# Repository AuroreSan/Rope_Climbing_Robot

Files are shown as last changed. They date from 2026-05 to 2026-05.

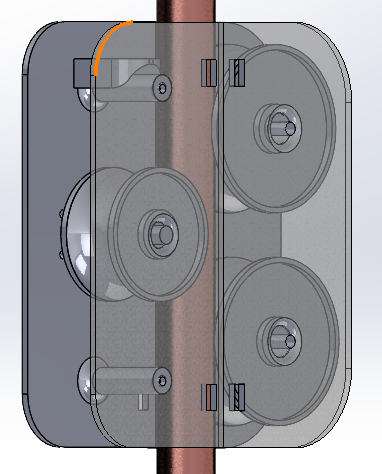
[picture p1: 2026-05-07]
w4.png

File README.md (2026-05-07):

# Rope Climbing Robot

A robotic system designed to autonomously climb ropes using 3D-printed components and motorized mechanisms.

## Overview

This project features a rope climbing robot with a modular body assembly, utilizing 3D printing technology with PLA or PETG materials for structural components. The robot is powered by 12V motors with H-bridge motor driver control.

## Assembly Instructions

### 3D Printed Components

Print the following STL files (without circuit cover):

| Component | Quantity | Infill |
|---|---|---|
| Back Body 1 Motor Placement | 1 | 15% |
| Front Body 1 Motor Placement | 1 | 15% |
| Front Body 2 Groove Wheel | 1 | 15% |
| Back Body 2 Groove Wheel | 1 | 15% |
| Motorised Pulley Wheel | 1 | 10% |
| Top Flat | 1 | 10% |
| Groove Wheel | 2 | 10% |
| M3 Body Pin Longer | 8 | 15% |
| Motor extension V3 | 8 | 25% |

#### Screws and Fasteners
- **2x** M3 Screw (10-20 mm) - Body assembly
- **4x** M3 Screw (50 mm) with nuts - Copper pipe connections
- **2x** M4 Screw (70 mm) - Front 2 and Back 2 body connections

#### Motors and Electronics
- **Motor:** 12V 107 RPM or 12V 200RPM
- **Motor Driver:** BTS7960 H-Bridge Motor Driver
- **Battery:** 12V 2400mAh NI-MH Rechargeable Battery with KET 2P Connection
- **LED:** 2 x (Red, Green) 
- **Passive Buzzer** 
- **Microcontroller:** Arduino nano 
- **Fuse:** L-12 Fuse Lamp 8V 250mA light Bulb or 10mA Fuse 
- **Switch:** 2 Push bottoms that can change the task of robot
- **Sensor** Time-of-Flight (ToF) Laser Ranging Sensor

*See the BOM (Bill of Materials) file for complete electronic components and specifications and link to the UK components*

## Assembly Steps

1. **Prepare 3D Printed Parts**
   - Ensure all printed components are clean
   - Verify proper fit of all mating surfaces

2. **Body Assembly**
   - Connect Front body 1 and Back body 1 using M3 screw of 20mm length 
   - Connect Front Body 2 and Back Body 2 using the M4 (50mm/70mm length). Make sure to put 2 big groove wheel in Body 2 before adding the scews. 

3. **Cross Body Connection**
   - Connect front and back body sections using 4x M4 70mm screws

5. **Motor and Pulley Assembly**
   - Mount the 12V 107 RPM motor on back Body 1. 
   - Install the motorised pulley wheel with the motor extension V3 inside
   - Cover all the wheels with non-slip mat cut off for better grip

6. **Electronics Integration**
   - Install BTS7960 H-Bridge Motor Driver
   - Connect motor power and control circuits per BOM specifications
   - Mount circuit components as specified in electronic assembly guide

## Bill of Materials (BOM)

Refer to the BOM document for a complete list of all electronic components and specifications.

## Design Features

- **Lightweight Construction:** 3D-printed PLA/PETG components reduce overall weight
- **Modular Assembly:** Separate front and back body sections allow for easy maintenance and customization
- **Efficient Drive System:** Motorised pulley with groove wheels for secure rope grip

## Project Structure

```
Rope_Climbing_Robot/
├── STL_Files/           # 3D printable model files
├── Electronics/         # Motor driver and control schematics
├── BOM.md              # Bill of materials
├── Assembly_Guide/     # Detailed assembly documentation
└── README.md           # This file
```

## Getting Started

1. Review and prepare all STL files for 3D printing
2. Print components 
3. Gather all hardware components listed in the BOM
4. Follow the assembly steps sequentially
5. Test motor operation before full deployment on rope

## Notes

- Ensure M3 and M4 fasteners are properly torqued but not over-tightened
- Verify motor rotation direction after assembly
- Test rope climbing functionality on a secured test rope before deployment

---

For questions or contributions, please refer to the project documentation or create an issue in the repository.

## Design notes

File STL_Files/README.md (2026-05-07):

# STL Files Directory

This directory contains all 3D printable STL model files for the Rope Climbing Robot project.

## Files to Add:
- Back Body 1 Motor Placement
- Front Body 1 Motor Placement
- Front Body 2 Groove Wheel
- Back Body 2 Groove Wheel
- Motorised Pulley Wheel
- Top Flat
- Groove Wheel
- M3 Body Pin Longer
- Motor extension V3

See README.md for printing specifications (infill percentages, quantities, etc.)

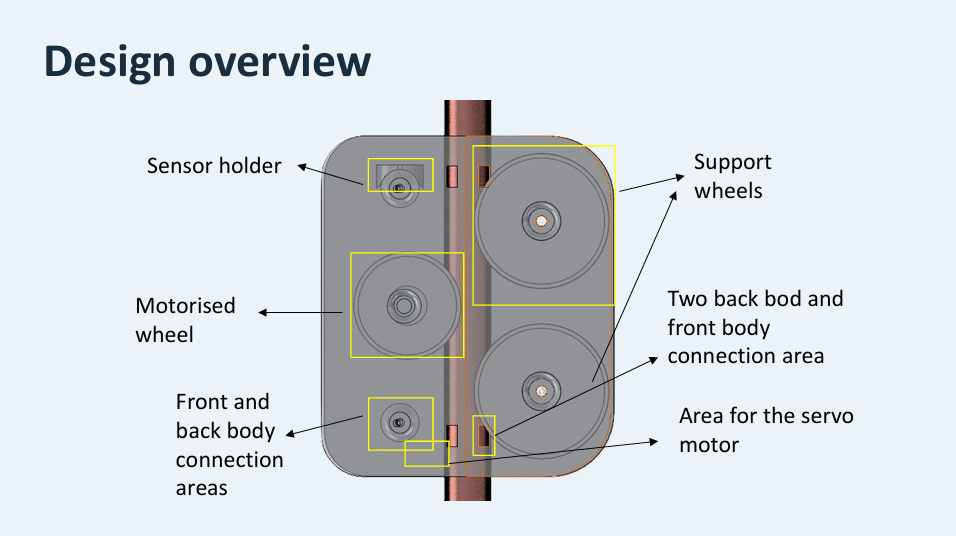
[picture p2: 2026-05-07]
design overview .png

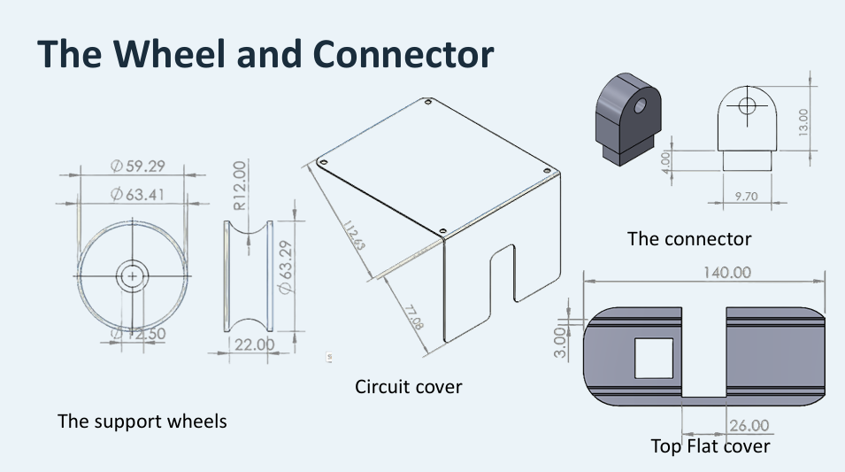
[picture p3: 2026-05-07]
wheel and connector.png

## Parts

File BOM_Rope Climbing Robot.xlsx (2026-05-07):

Bill of Materials – Robot Project (UK Suppliers)
Item | Qty Used | Part Name | Description | Pack Size | Pack Price (£) | Unit Cost (£) | Line Total (£) | Supplier / Link
1 | 1 | DC Gear Motor 12V 200 RPM | sourcing map JGB37-520 micro gear box DC motor, 12V, 200 RPM, D-shaped output shaft, metal gearbox | 1 | £16.00 | £16.00 | £16.00 | Amazon UK (sourcing map) (https://www.amazon.co.uk/dp/B0FSXFKT89)
2 | 1 | BTS7960 H-Bridge Motor Driver | Dual BTS7960 43A H-bridge motor driver module, 6–27V input, PWM up to 25kHz, current sense and thermal protection | 1 | £7.99 | £7.99 | £7.99 | Amazon UK (Fasizi) (https://www.amazon.co.uk/Fasizi-BTS7960-Power-Driver-Module/dp/B09Z2FBCJ3)
3 | 1 | Red 5mm LED | Ultra-bright 5mm red LED, ~2V Vf at 20mA. Sold in pack of 10 – cost shown is for 1 used | 10 | £2.50 | £0.25 | £0.25 | The Pi Hut (https://thepihut.com/products/ultra-bright-led-5mm-red-10-pack)
4 | 1 | Green 5mm LED | Ultra-bright 5mm green LED, ~3.2V Vf at 20mA. Sold in pack of 10 – cost shown is for 1 used | 10 | £2.50 | £0.25 | £0.25 | The Pi Hut (https://thepihut.com/products/ultra-bright-led-5mm-green-10-pack)
5 | 1 | Passive Buzzer 5V | Breadboard-friendly 5V passive piezo buzzer, 4–8V rated, 30mA – tone() compatible with Arduino | 1 | £3.00 | £3.00 | £3.00 | The Pi Hut (https://thepihut.com/products/buzzer-5v-breadboard-friendly)
6 | 1 | ELEGOO Pre-soldered Nano (USB-C) | ELEGOO Nano V3 board with pre-soldered headers, ATmega328P + CH340, USB-C, Arduino IDE compatible. Sold in 3-pack – cost shown is for 1 used | 3 | £17.99 | £6.00 | £6.00 | Amazon UK (ELEGOO) (https://www.amazon.co.uk/ELEGOO-Pre-soldered-ATmega-Compatible-Arduino/dp/B0D7Q6BGW8)
7 | 1 | Glass Tube Fuse | 25pcs Fast Blow Glass Fuses 6 * 30mm 250V 10A Quick Tube Fuse Assortment Kit | 25 | £5.39 | £0.22 | £0.22 | Amazon UK (https://www.amazon.co.uk/Innfeeltech-25pcs-Glass-Fuses-Assortment/dp/B0CQL13XSP?cv_ct_cx=10A%2BFuse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)
8 |  | ToF Laser Sensor | VL53L0X Time-of-Flight (ToF) Laser Ranging Sensor Breakout 940nm VL53L0X V2 Laser Distance Module I2C IIC | 1 | £3.99 | £3.99 | £3.99 | Amazon UK (https://www.amazon.co.uk/iHaospace-VL53L0X-Flight-Breakout-Distance/dp/B07DYM28VR?s=industrial)
9 | 2 | 12mm Tactile Push Button | 12mm square momentary tactile switch, 6mm tall, breadboard/PCB compatible. Sold in pack of 10 – cost shown is for 2 used | 10 | £2.50 | £0.25 | £0.50 | The Pi Hut (https://thepihut.com/products/tactile-switch-buttons-12mm-square-6mm-tall-x-10-pack)
10 | 1 | 12V 2400 mAh Ni-MH Battery (KET 2P) | MXJFYY 12V 2400mAh Ni-MH rechargeable battery pack with KET 2P connector and USB charging cable – powers motor + electronics from a single 12V rail | 1 | £18.99 | £18.99 | £18.99 | Amazon UK (MXJFYY) (https://www.amazon.co.uk/MXJFYY-2400mAh-Connector-Construction-Climbing/dp/B0DJVS6R32)
 |  |  |  |  |  | Total cost of parts used: | £57.18
 |  |  |  |  |  | Total if buying full packs: | £80.85

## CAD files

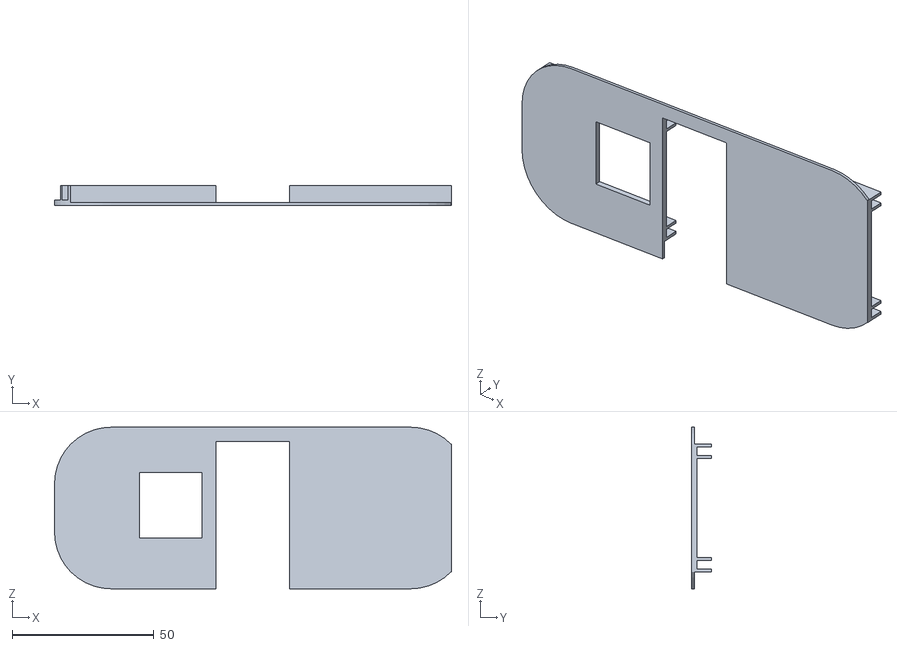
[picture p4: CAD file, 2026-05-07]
STL_Files/Top Flat.STL
140.0 x 7.00 x 57.0

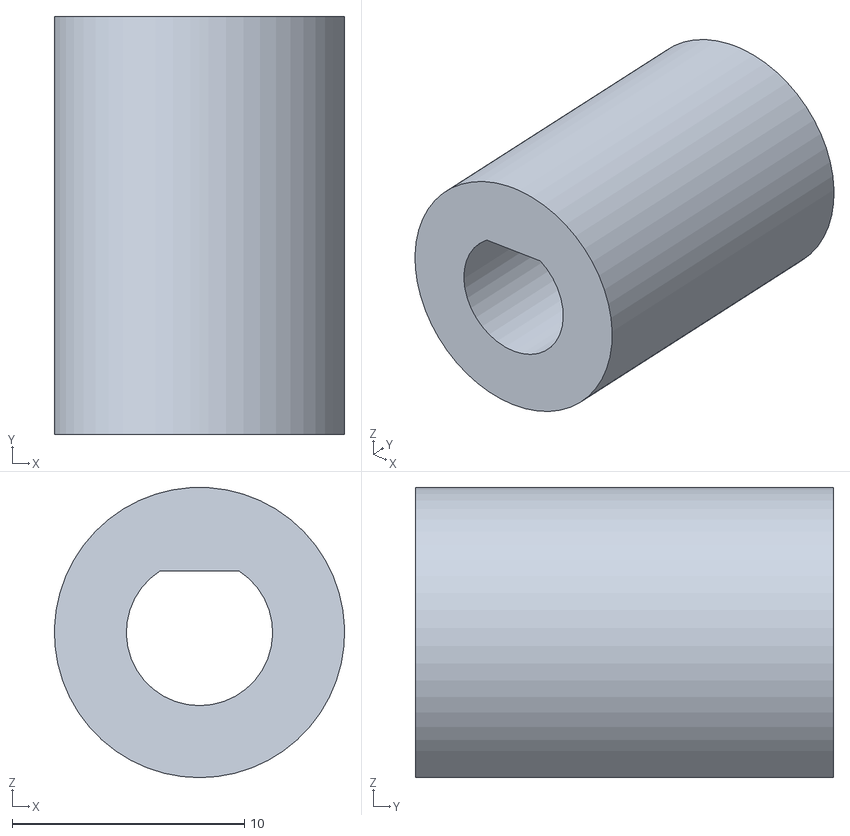
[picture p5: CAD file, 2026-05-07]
STL_Files/Motor extension V3.STL
12.5 x 18.0 x 12.5

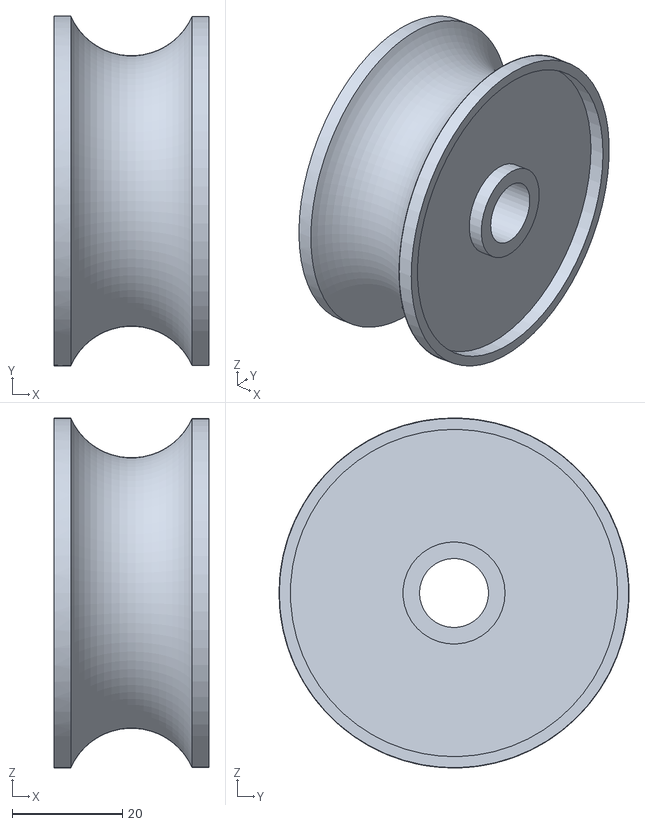
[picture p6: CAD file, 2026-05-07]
STL_Files/Groove wheel.STL
28.0 x 63.4 x 63.4

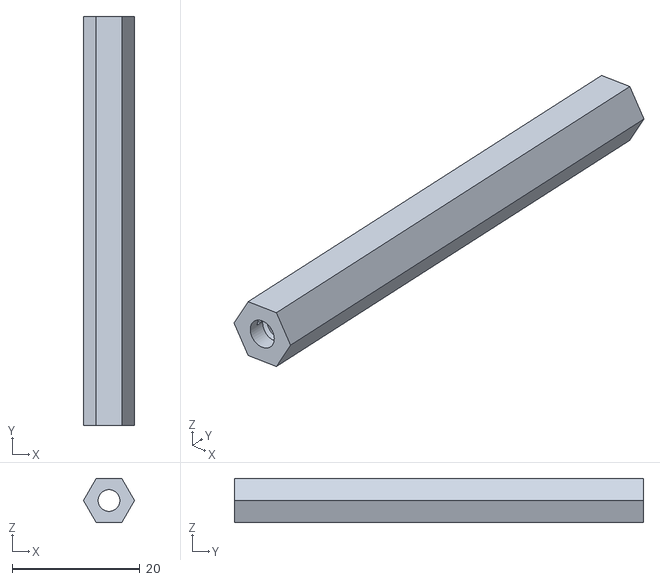
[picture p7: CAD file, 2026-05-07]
STL_Files/Cover support.STL
8.00 x 64.0 x 6.93

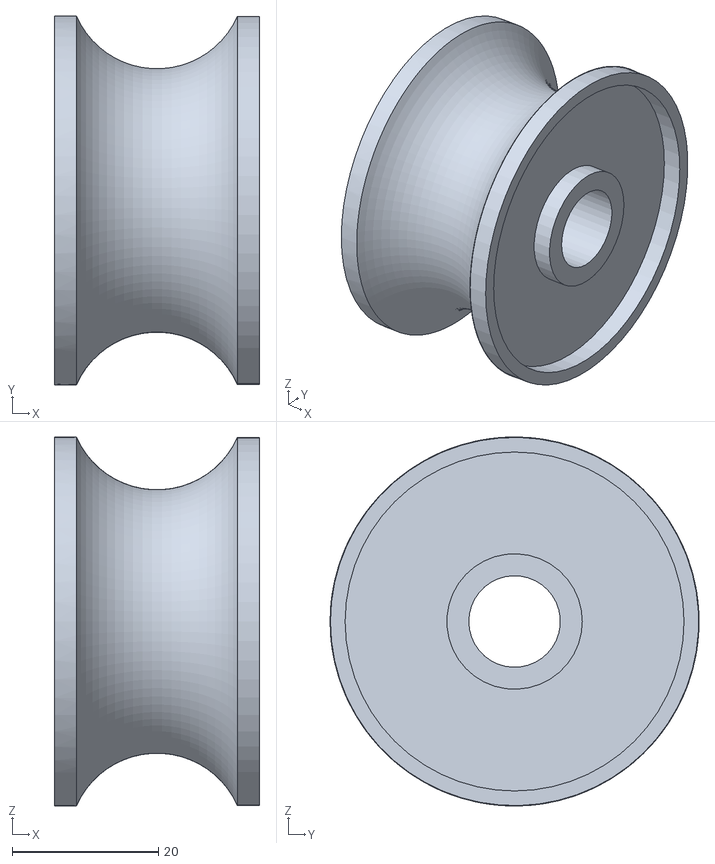
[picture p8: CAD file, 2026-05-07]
STL_Files/Motorsied pully wheel.STL
28.0 x 50.4 x 50.4

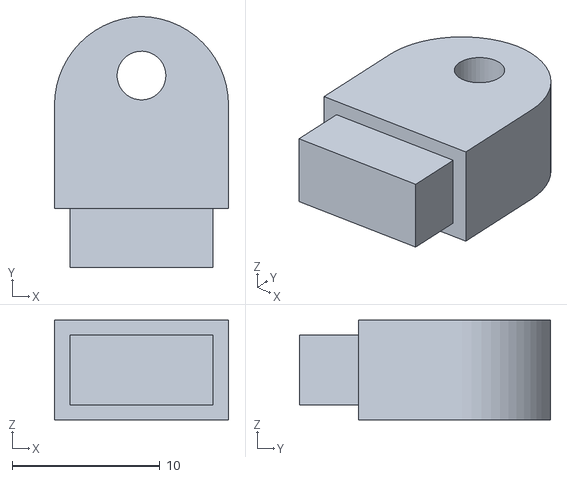
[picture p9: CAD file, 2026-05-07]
STL_Files/M3 Body Pin longer.STL
11.8 x 17.0 x 6.75

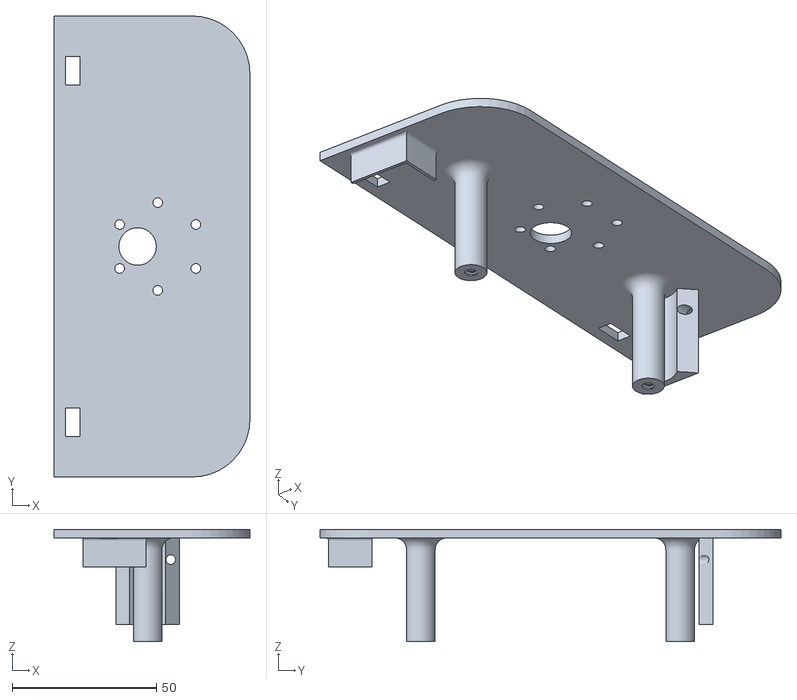
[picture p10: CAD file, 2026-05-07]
STL_Files/Back Body 1 Motor Placement .STL
68.0 x 160.0 x 39.0

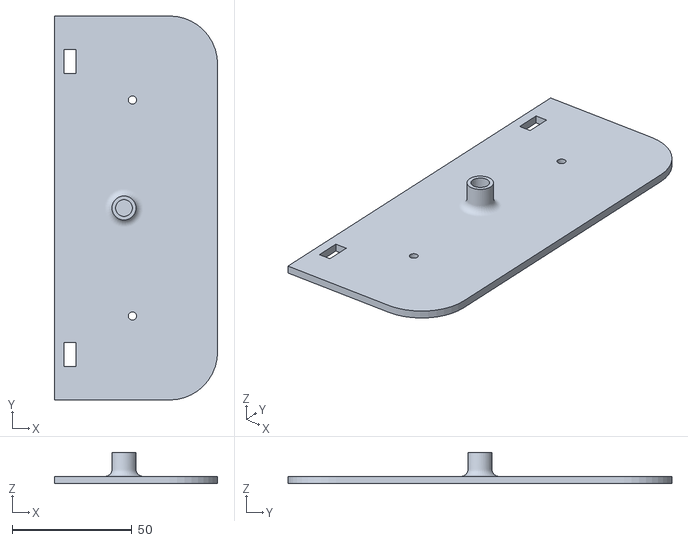
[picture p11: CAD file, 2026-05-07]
STL_Files/Front Body 1 Motor Placement.STL
68.0 x 160.0 x 13.0

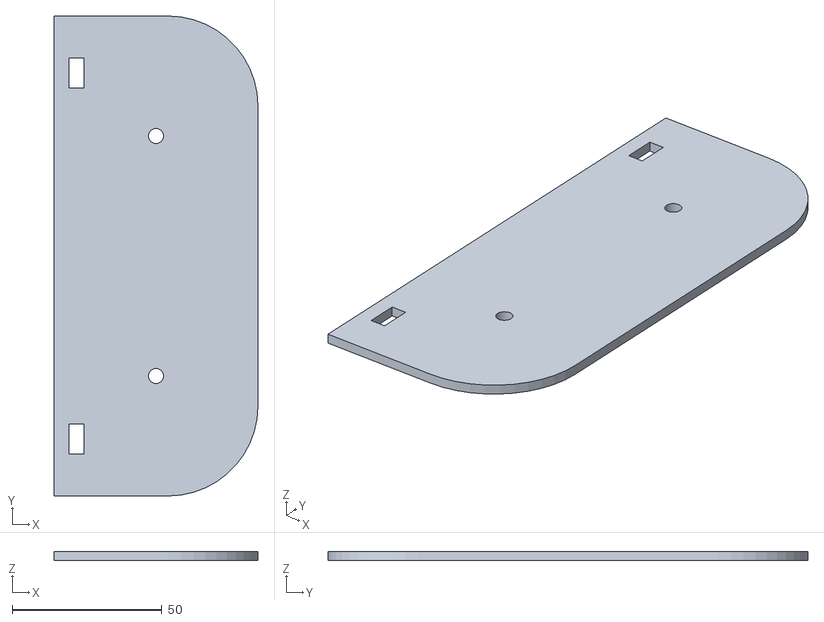
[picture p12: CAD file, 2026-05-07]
STL_Files/Back Body 2 Groove Wheel .STL
68.0 x 160.0 x 3.00

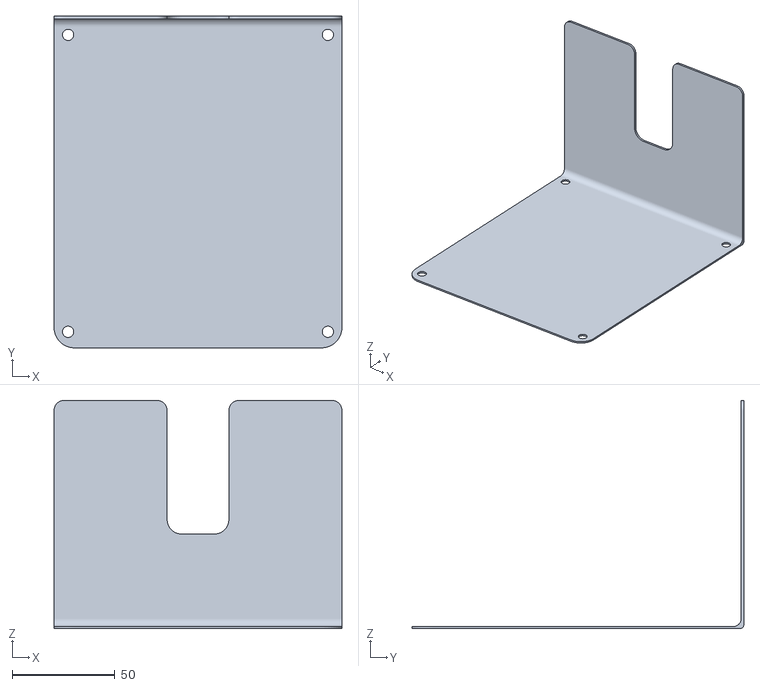
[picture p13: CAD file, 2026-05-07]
STL_Files/Circuit cover Part.STL
140.0 x 161.3 x 111.0

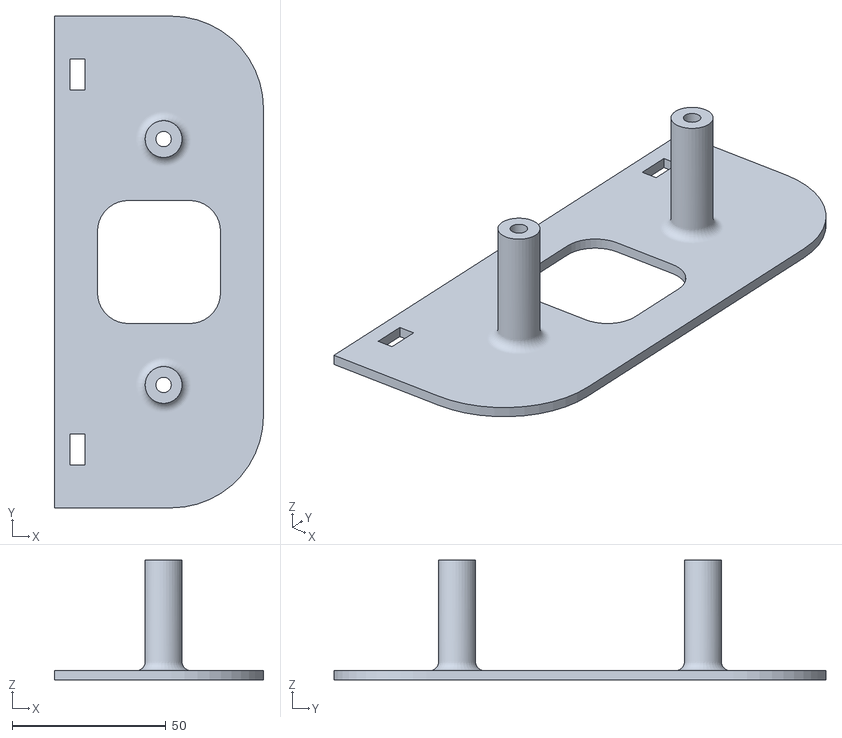
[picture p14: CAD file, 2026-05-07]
STL_Files/Front Body 2 Groove wheel.STL
68.0 x 160.0 x 39.0

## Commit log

2026-05-07 Revise README for STL infill and assembly instructions
    Updated infill percentages for various STL components and revised assembly instructions for clarity. Added additional hardware details and improved formatting.
2026-05-07 Create STL_Files directory for 3D printable model files
2026-05-07 Add files via upload
    Electrical components list
    [BOM_Rope Climbing Robot.xlsx]
2026-05-07 Fix typo in README for switch description
2026-05-07 Add files via upload
    1 DC Gear Motor 12V 200 RPM
    1 BTS7960 H-Bridge Motor Driver
    1 Red 5mm LED
    1 Green 5mm LED
    1 Passive Buzzer 5V
    1 ELEGOO Pre-soldered Nano (USB-C)
    1 Glass Tube Fuse
    ToF Laser Sensor
    2 12mm Tactile Push Button
    1 12V 2400 mAh Ni-MH Battery (KET 2P)
    [BOM_Rope Climbing Robot.xlsx]
